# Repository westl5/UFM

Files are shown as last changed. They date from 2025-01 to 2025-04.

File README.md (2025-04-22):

# UFM - Unidentified Flying Mouse
**McMaster University Electrical & Computer Engineering Capstone Team 10**

<p align="center">
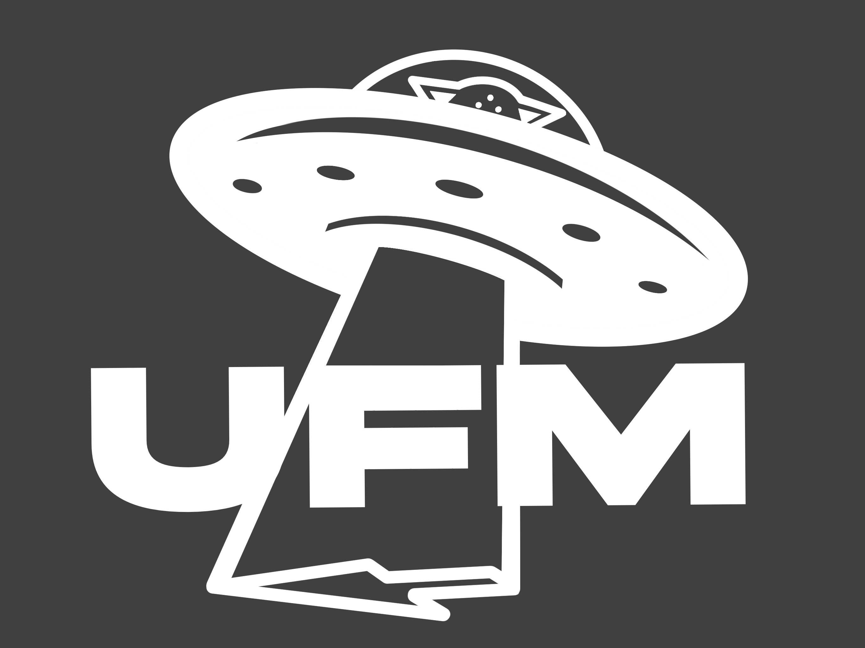
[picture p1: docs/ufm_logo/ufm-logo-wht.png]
UFM Logo
  
</p>

## Project Overview
UFM (Unidentified Flying Mouse) is a wrist-worn computer input device designed for individuals with limited hand dexterity, those who have undergone hand amputation, or those who were born without a hand. The system converts movements from the arm to mouse functions and sends mouse commands to the user's PC over bluetooth. 

## Project Video
https://github.com/user-attachments/assets/12428ccc-8710-40ed-a4b3-f343b9fc400c

([Full Video](https://youtu.be/52ZPP2TyDK4))

## Team Members
- Luke West ([@westl5](https://github.com/westl5))
- George Gill ([@georgegill](https://github.com/georgegill))
- Matthew Yu ([matthyu2002](https://github.com/matthyu2002))
- Ryan Xu ([@RyanXu02](https://github.com/RyanXu02))
  
## Contact
For more information about the UFM project, please contact any of the team members listed above.

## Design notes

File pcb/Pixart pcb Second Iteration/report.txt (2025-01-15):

Info: Processing symbol 'J2:'.
Info: Processing symbol 'U1:'.
Error: Cannot add J2 (no footprint assigned).
Error: Cannot add U1 (no footprint assigned).

Info: Total warnings: 0, errors: 2.

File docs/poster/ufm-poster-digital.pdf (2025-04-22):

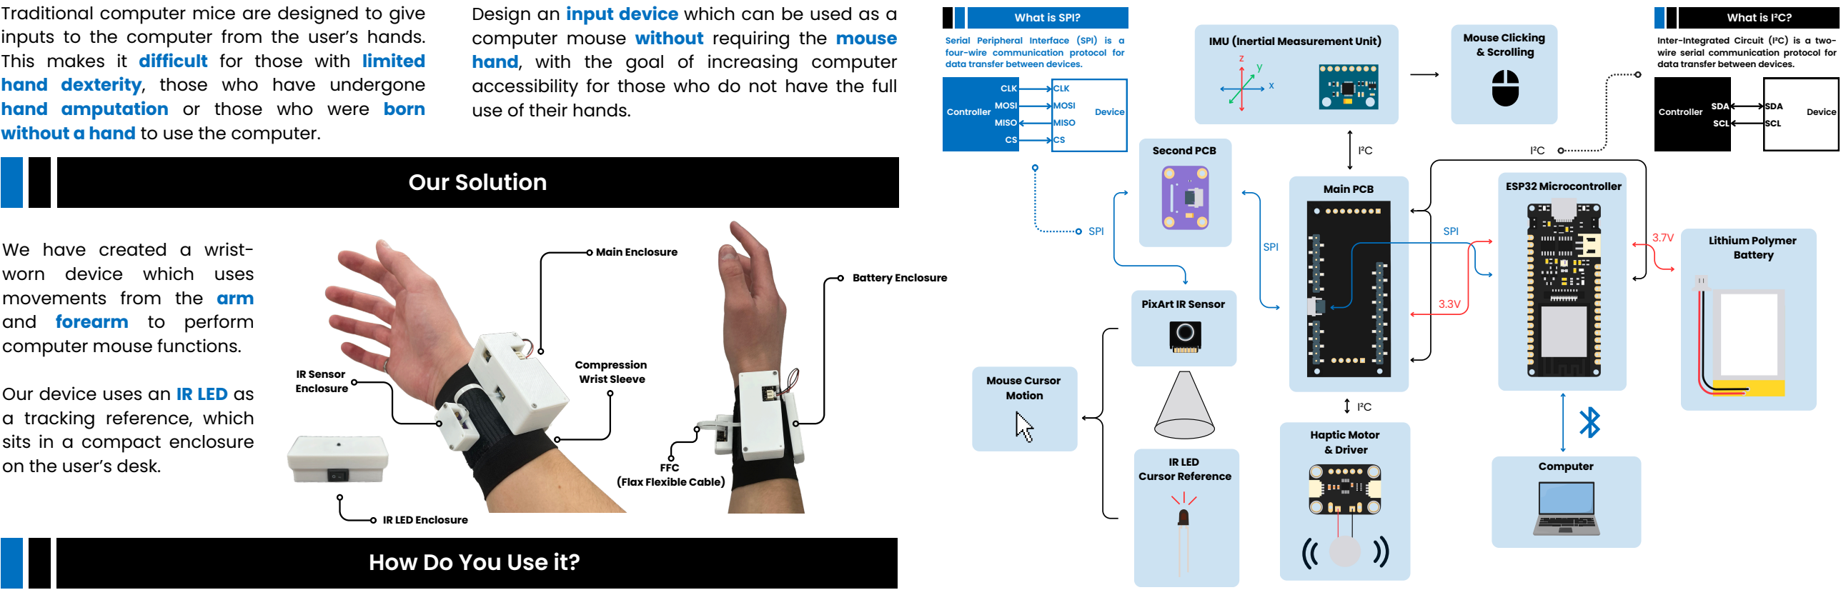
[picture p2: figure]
CLK MOSI MISO CS; ObjPercotbivleem; SPI; I²C; IMU (Inertial Measurement Unit); Main PCB; Haptic Motor & Driver; Computer; Lithium Polymer Battery; ESP32 Microcontroller; IR LED Cursor Reference; Mouse Clicking & Scrolling; Mouse Cursor Motion; PixArt IR Sensor; Second PCB; hand amputation or those who were born without a hand to use the computer.; use of their hands.; We have created a wrist- worn device which uses movements from the arm and forearm to perform computer mouse functions.; Our device uses an IR LED as a tracking reference, which sits in a compact enclosure on the user’s desk.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
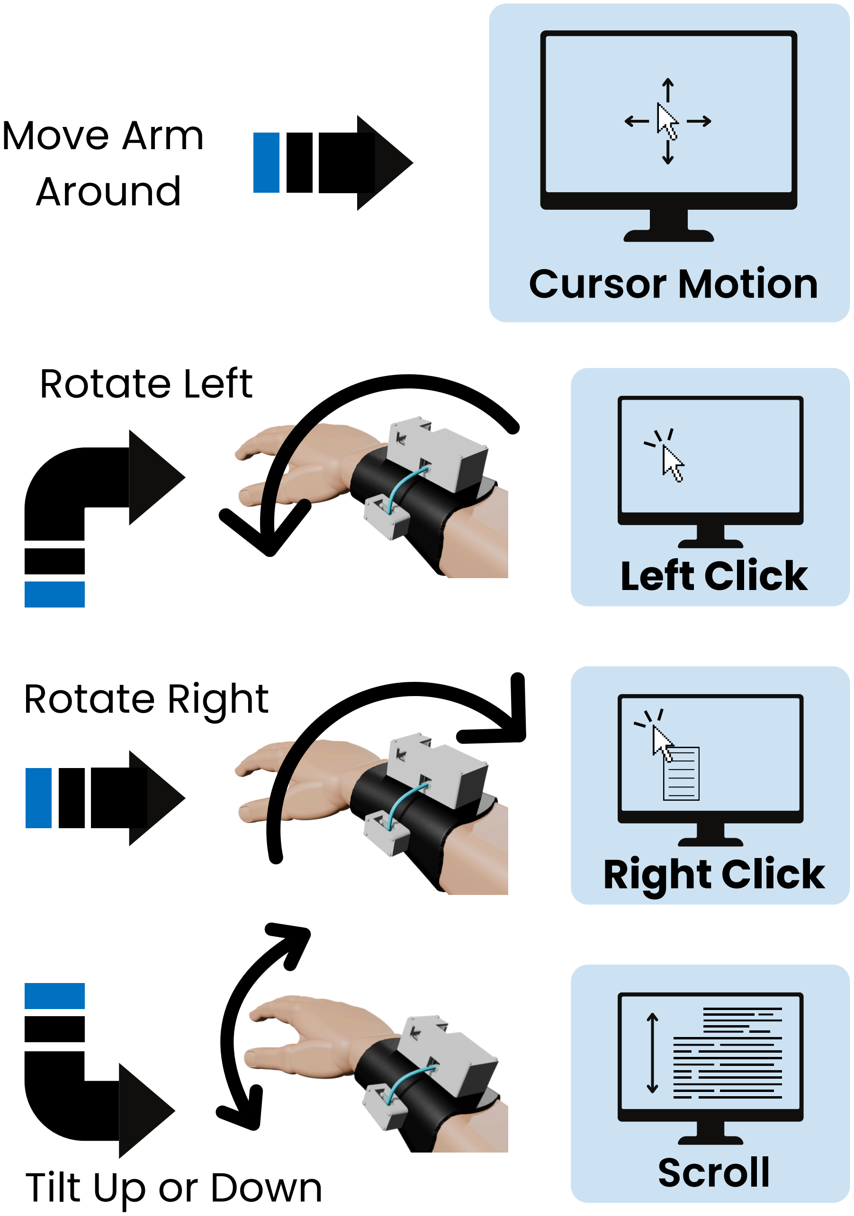
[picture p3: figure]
Move Arm Around; Cursor Motion; Left Click; Right Click; Scroll; Rotate Left; Rotate Right; Tilt Up or Down

### OObbjejeccttivivee

### OObbjejecctitvivee

References | + Video

### Motivation

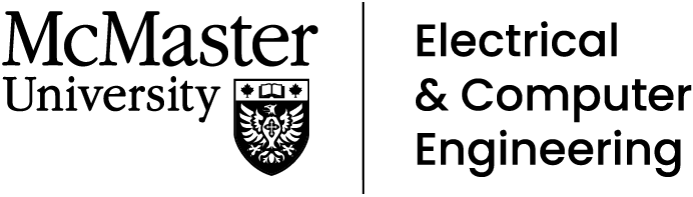
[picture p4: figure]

Hold Still (0.5s)

# unidentified flying mouse

### ECE Group 10 (Jom & Terry) - George Gill - Luke West - Ryan Xu - Matt Yu

### System Overview

### Project Video

Software Design Choices | Physical Design Choices

Traditional computer mice are designed to give inputs to the computer from the user’s hands. This makes it difficult for those with limited hand dexterity, those who have undergone

Design an input device which can be used as a computer mouse without requiring the mouse hand, with the goal of increasing computer accessibility for those who do not have the full

Inter-Integrated Circuit (I²C) is a two-

Small | form | factor | and | lightweight
construction for a comfortable fit. Compression sleeve allows users with various wrist sizes to put-on the mouse using only one arm.
Enclosures secured with velcro for easy attachment and removal.
Battery power allows for wireless operation for an estimated 8hrs with a 1100mAh LiPo battery.

### References & Acknowledgements

Codebase entirely contained to the ESP-32 meaning no extra software is needed from the user: Just pair with the device using bluetooth and the mouse is ready to use. Mouse movement calculation is very simple, allowing for low computation time and a very responsive mouse cursor.
Cursor movement is separated from other functions with a wait time, limiting mis-inputs.

How Does It Work?

Cursor Mode
(Default)

Gesture Mode
(User Prompted by
Haptic Vibration)

(If No Gesture,
Return to Cursor
Mode)

The PixArt IR Sensor Tracks an 850nm IR LED at 200fps and sends its x-y coordinates to the ESP-32 Microcontroller.
Each coordinate is compared to the previous one and the
difference is used to determine the direction and magnitude to of mouse movement to apply. If the mouse remains still for 0.5s, the user is prompted via haptic vibration to perform a gesture to click or scroll.
An IMU measures acceleration and angular velocity to capture each gesture.
The mouse cursor or gesture commands are sent to the PC by the ESP-32 over bluetooth.
Motivation | Objective
B. Trzynadlowski, “PixArt PAJ7025R2 6dof Tracking Demo with Arduino and Windows,” GitHub. Accessed: Jan. 03, 2025. [Online]. Available: https://github.com/trzy?tab=repositories&q=PixArt&type=&language=&sort=

University of Pittsburgh the McGowan Institute For Regenerative Medicine, “Prosthetic Hook Mouse for people with upper-limb amputations,” https://mirm-pitt.net/prosthetic-hook-mouse-for-people-with-upper-limb-amputations/ (accessed Oct. 20, 2024).

L. M. Keita, B. Alcantara, and M. G. Salazar, “Wireless Mouse for people with upper limb amputation,”://www.dlsu.edu.ph/wpcontent/uploads/pdf/conferences/ditech/proceedings/volume-3/paper-3.pdf (accessed Oct. 20, 2024).

Special thanks to the Thode Makerspace for providing resources such as 3D printers and soldering equipment.

[1]

[2]

[3]

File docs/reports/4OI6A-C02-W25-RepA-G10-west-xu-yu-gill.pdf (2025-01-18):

## ELECENG 4OI6A ECE Capstone Progress Phase A Ergonomic Computer Mouse for Individuals Lacking Hand Dexterity

Instructor: Dr. Abdelhadi
Section: C02
Group 10

Luke West – westl5 – 400310803 Ryan Xu – xur76 – 400309994 Matthew Yu – yum77 – 400322243 George Gill – gillg62 – 400327563

Date: January 17th, 2024

Table of Contents

## Abstract and Summary of the Design

The computer mouse is a common household tool which has very straightforward operation for most of the population. But for those with limited finger and hand dexterity, or those lacking a hand entirely, the traditional design can be difficult to use. We propose a wrist band mounted design, which eliminates the use of the hand entirely, placing emphasis on use of the forearm instead. Our design aims to accomplish all normal functions of the traditional mouse, namely cursor movement, clicking, and scrolling. The mouse movement is achieved by moving the forearm in the horizontal plane, clicking is achieved via rotation about the forearm axis, and scrolling is achieved via pitch angle of the forearm. Our device is controlled via ESP32 microcontroller, which takes input from a PixArt PAJ7025R3 multiple objects tracking IR sensor, and MPU 6050 inertial measurement unit, and sends mouse input commands to the user’s computer over Bluetooth (or UART via USB-C). The device also includes tactile clicking feedback via a haptic LRA motor.

## Current Status

## Implementation

The following is a list of notable achievements towards the project in phase A.
- Procurement of main components which are shown in the expenditure section
- Design and acquisition of PCB to interface with PixArt PAJ7025R3 sensor
- Successful communication with PixArt PAJ7025R3 sensor and 2D visualization of tracked objects
- Completion of overall circuit design and schematic
- Simulation of mouse cursor tracking in Python
- Demonstration of haptic feedback based on rotation of IMU
- Prototype 3D models of wrist band to hold all components, as well as an initial fourpoint 3D-model of structure to hold four IR LEDs
- Testing with ESP-32 Bluetooth capabilities, including moving a mouse cursor with pre-programmed movements

## Scheduling

The Gantt chart illustrates the project's progress over the last quarter of 2024. We are generally on schedule, with a few minor setbacks that have altered the forthcoming schedule. Setbacks from procuring parts and some issues interfacing with the PixArt sensor caused a significant delay in creating a working prototype. Additionally, this also halted the hardware/software assembly tasks.

This will cause a change in the testing stage, as we will cut into this phase to crash the uncompleted tasks. This is reflected in the new Gantt chart, where tasks "Develop

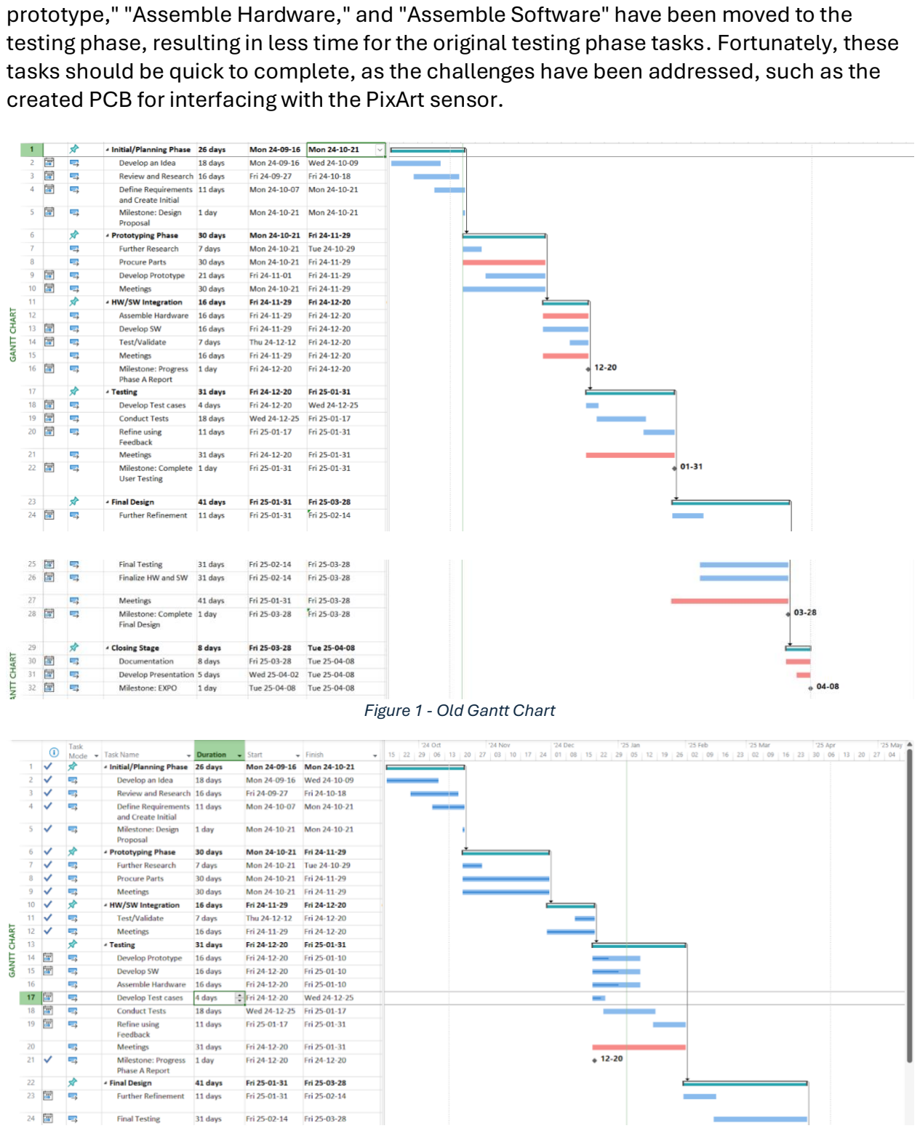
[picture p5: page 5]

prototype," "Assemble Hardware," and "Assemble Software" have been moved to the testing phase, resulting in less time for the original testing phase tasks. Fortunately, these tasks should be quick to complete, as the challenges have been addressed, such as the created PCB for interfacing with the PixArt sensor.

Figure 1 - Old Gantt Chart

Figure 2 - Updated Gantt Chart

## Expenditure

Current Spending

To date, our group has acquired the following components and materials essential to the prototyping and testing phases of the project. For price break down please see the bill of materials.

- Reflective Tape: Used to test how accurate the PixArt sensor tracks reflections from the IR emitter.
- IR Emitters & Receiver Package: Transmits IR for tracking purposes with the PixArt sensor.
- ESP32: Controller used for interacting with other devices and processing sensor outputs.
- Motor Unit: Provides user feedback through vibrations for interaction with the system.
- Motor Driver: Controls the motor units for providing feedback.
- Motor Driver Cable: Connects the motor driver to the system for signal transmission.
- PixArt Test PCB: Connects the PixArt sensor to the system as it does not come with a pre-made connector.
- Heat Resistant Tape: Protects components during the soldering process to avoid heat damage.
- Flux Paste: Improves soldering quality, ensuring clean and strong connections.
- IR Emitter (860NM): Offers a better NM rating for the sensor to detect, compared to previous emitters.
- PixArt Sensors: Main sensor for tracking movement in the system.

The total expenditure amounts to $260.16 CAD for the prototyping and testing phase of the project.

Team Member Personal Contributions & School Resources

Several team members have provided personal materials that they already owned to support the project which has significantly reduced overall costs. These materials include:
- Helping Hand Station for Soldering
- Soldering Iron
- Solder Wire
- Breadboards
- Capacitors
- Resistors
- Wires
- 3D Printer + Filament
- Makerspace Materials

Projected Future Expenses

Our team estimates an additional $200 CAD for the following:
- Custom PCB for wrist mounting (Possible flexible PCB)
- Purpose: To integrate all components into a compact, wrist friendly design. Flex PCB would improve comfort and durability.
- Smaller and more power efficient ESP32
- Purpose: Reduce size and device and extend battery life
- Flexible and comfortable material for wrist strap
- Purpose: Provide user-friendly and ergonomic strap so mouse can be used for prolonging periods of time.
- Battery
- Purpose: Power device while maintaining portability and compactness.

## Technical Implementation

## Physical Design

Circuit Design and Hardware

The electrical schematic created in KiCAD outlines the configuration of the microcontroller, sensors, and other components. Acting as a map, it will provide significant assistance during the physical wiring of the device. There are two critical aspects of the schematic. Firstly, the design that will be located on the wrist. This includes the PixArt sensor, microcontroller, haptic motor drivers, motors, IMU, and a battery. The microcontroller interfaces with all components through its various GPIO pins and is powered by an external lithium-polymer battery or USB-C cable connected to the computer. The KiCAD schematic closely follows the rough schematic, with slight tweaks. Additionally, our group checked if the FireBeetle2 and Adafruit E-Feather have similar configurations due to their benefit of onboard voltage regulator and noticed that the FireBeetle 2 is almost a perfect fit.

At the current stage, all testing is being done using a Node MCU development board which does not have built in battery implementation. We determined that an implementation including the battery is optional for the completion of the project, as a wired design has its own benefits, and allows for testing without draining a battery which could get expensive. In the later stages of the project, we intend to include a battery and communicate using Bluetooth, as this should be more physically comfortable for the user.

Note: The microcontroller used in the KiCAD schematic is the FireBeetle 2 ESP32-E. The FireBeetle 2 has an onboard voltage regulator, reducing the input voltage from the selected 3.7 volts to the desired 3.3 volts. It also has a built-in PH2.0 lithium battery connector interface and an on-board charging circuit, allowing easy battery charging using the USB-C port. This eliminates the need for an external voltage regulation circuit shown on the original rough schematic which would be required using the current ESP32 microcontroller development board, reducing the footprint of the schematic.

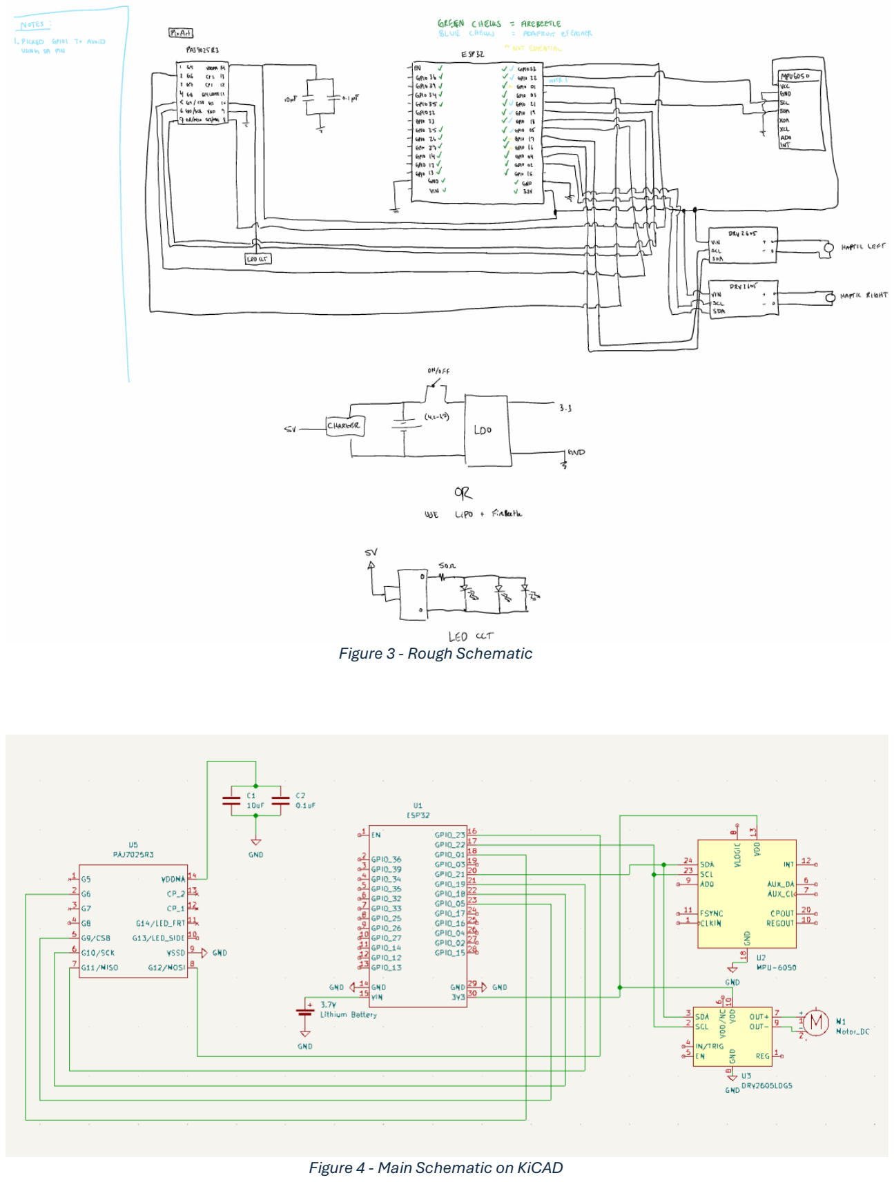
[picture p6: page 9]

Figure 3 - Rough Schematic

Figure 4 - Main Schematic on KiCAD

The second aspect of the schematic displays the IR LED circuit. The LEDs are configured in a parallel circuit and powered using an external lithium battery. Each diode has a 100-ohm resistor to limit the current to 8mA. The current can be altered using additional resistors if required. Lastly, a switch controls if the circuit is active, allowing the user to turn on/off the circuit accordingly. This schematic may undergo changes in the future following the prototyping stage.

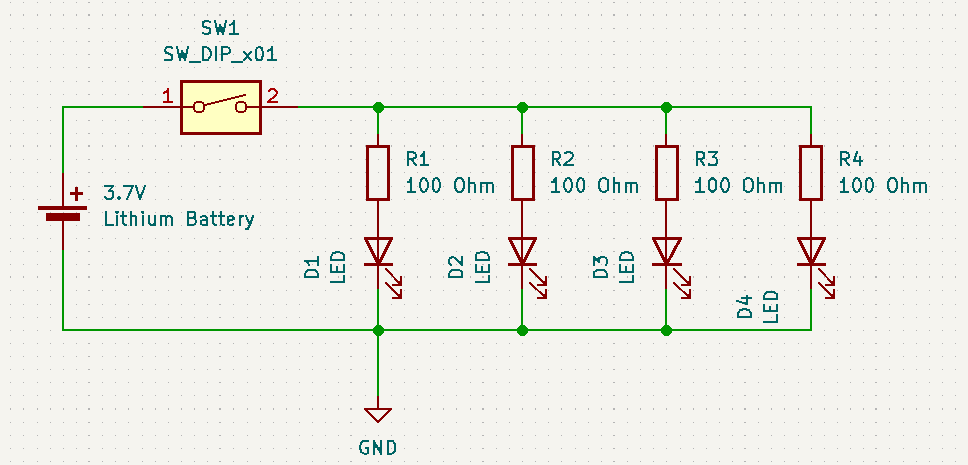
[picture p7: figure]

Figure 5 - Schematic of IR LED Circuit on KiCAD

PixArt Custom PCB Design
In the early stages, our group struggled to interface with the PixArt PAJ7025R3 sensor due to limited knowledge and a lack of pre-made connectors. The datasheet provided minimal guidance, leaving us uncertain about how to proceed. Eager to advance, we tried various methods, including soldering wires directly, creating a custom connector, and reaching out to companies for support. However, these attempts failed, and one sensor was damaged in the process. The long lead time for a custom PCB added further delays, but we ultimately determined that designing a custom PCB was the most reliable solution. A project by Bart Trzynadlowski using the PAJ7025R2 variant of our sensor was referenced in the design[1].
From doing research, our group decided to learn KiCAD to design the PCB as it is known as a beginner friendly software. The custom PCB that was created includes:
- Two-layer construction: A compact and efficient layout for seamless integration. Custom through-hole connector: Designed to provide a stable and secure connection to the sensor.
- Pin header connection: Precision-routed traces ensuring reliable communication between the sensor and the system.
- Clear labeling: Each trace and pin has been clearly labeled to improve assembly accuracy and facilitate future troubleshooting.

This process not only addressed the immediate need for a stable connection to the sensor but also significantly enhanced my skills in PCB design. Despite the initial setbacks, this solution enabled us to move forward with the project, exemplifying our ability to overcome technical challenges through proactive problem-solving and innovation. The experience has been invaluable in ensuring that our system is both reliable and scalable as we continue development. An image of the PCB design can be found below with more details of the design in the appendix.

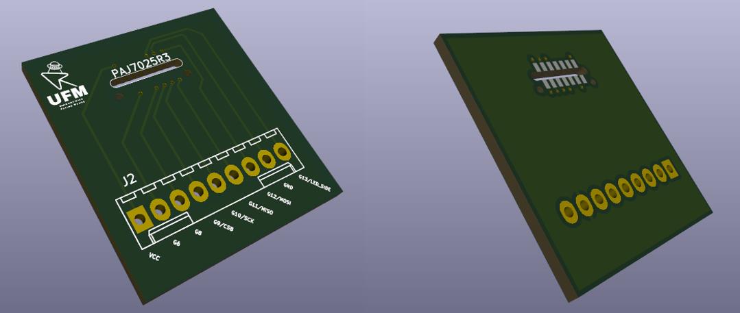
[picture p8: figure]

Figure 6 - Custom PixArt Sensor PCB Front and Back View Iteration 1

PixArt PCB Redesign
After a two-week lead time, the PCBs were delivered, and our team successfully soldered the sensor onto the custom design. This first iteration of the PCB was intentionally overdesigned to account for all potential pin configurations we deemed useful for the sensor. However, through extensive testing and prototyping, we identified several opportunities for optimization:
1. Pin Reduction: Of the original 9 pins, only 6 were necessary for the sensor’s operation, allowing us to simplify the design and reduce unnecessary traces.
2. Proximity of Capacitors: Following recommendations from the sensor’s datasheet, we ensured that decoupling capacitors were placed as close to the sensor as possible to improve signal stability and reduce noise. Proper placement of capacitors is critical for mitigating power supply fluctuations and ensuring consistent performance [2].
3. FFC/FPC Cables: To enhance flexibility and reduce weight, we transitioned from traditional pin headers to flat flexible cables (FFC) and flexible printed circuits (FPC). These components are significantly thinner and more compact, making them ideal for wearable applications where size and weight are critical considerations [3], [4].
4. Mounting Holes: Strategically placed mounting holes were added to secure the PCB within the 3D-printed housing, ensuring stability during operation [5].

Capacitor Selection
For the second iteration, we added two capacitors to the design: a 10 µF capacitor and a 0.1 µF capacitor. The selection process for these components was crucial to optimizing the PCB's performance. Here is an overview of the types of capacitors we considered and the reasoning behind our final choice:
- Ceramic Capacitors:
- Pros: Compact, low cost, and excellent frequency response. They are ideal for decoupling applications due to their low equivalent series resistance (ESR).
- Cons: Limited capacitance range, and their capacitance can vary with voltage (known as the DC bias effect).
- Tantalum Capacitors:
- Pros: High capacitance in a small form factor, stable performance, and low leakage current. They are well-suited for applications requiring bulk storage and stability.
- Cons: More expensive than ceramic capacitors and can be sensitive to voltage spikes, potentially leading to failure.

- Electrolytic Capacitors:
- Pros: High capacitance values and relatively low cost. Suitable for bulk storage.
- Cons: Larger size, shorter lifespan, and higher ESR compared to other types.
- Film Capacitors:
- Pros: Very stable and reliable, with excellent tolerance.
- Cons: Large size and relatively high cost, making them unsuitable for compact designs.

We ultimately chose a ceramic capacitor (0.1 µF) for decoupling due to its excellent frequency response and low ESR, which are crucial for filtering out high-frequency noise. For bulk capacitance, we opted for a tantalum capacitor (10 µF) due to its small form factor and stable performance. This combination balanced cost, size, and functionality [2].

Connector Selection: FFC vs. FPC

Transitioning to FFC/FPC connectors significantly improved the compactness and weight of the design. These connectors are widely used in applications requiring thin, flexible connections.
- Flat Flexible Cables (FFC): Comprised of flat and flexible ribbon-like cables, FFC connectors are simple to use and cost-effective[3], [4].
- Pros: Low profile, highly flexible, and widely available in standard configurations.
- Cons: Limited durability and can be prone to damage if handled improperly.
- Flexible Printed Circuits (FPC): Like FFC but more robust, FPC connectors use circuits printed directly onto a flexible substrate [3], [6].
- Pros: Higher durability, better electrical performance, and customizable configurations.
- Cons: More expensive and requires precise manufacturing processes.

For our application, FFC was chosen due to its simplicity and cost-effectiveness, aligning with the lightweight and compact nature of our design.

When it came to picking the type of FFC connector, there were a plethora of them to look at. Our team considered the pros and cons of each locking feature:
- Back lock: A simple, rear-entry locking mechanism where the cable is inserted and locked by engaging a mechanism at the back of the connector.
- Pros: Provides a solid, secure lock with low chances of accidental disconnection. It’s also relatively straightforward and easy to implement.
- Cons: In some designs, it might be harder to disengage or re-connect, especially in tight spaces.

- Flip lock: A locking mechanism where a flap or lever is flipped over the cable to lock it in place.
- Pros: Simple to use and offers a quick connection. It’s also quite secure in some designs.
- Cons: Can be bulky, and the flipping motion might wear out over time, especially in high-usage applications.
- Flip lock, Back lock: Combines the flip mechanism with a back-locking feature to secure the cable.
- Pros: Provides both secure locking and ease of assembly/disassembly.
- Cons: Combining both mechanisms can lead to a larger connector footprint, potentially affecting space and weight-sensitive designs.
- Latch Lock: A latch engages to lock the connector in place, often requiring the latch to be pulled or pressed to disengage the cable.
- Pros: Ensures a firm connection, preventing the cable from accidentally detaching.
- Cons: Can add complexity to the connector, potentially requiring more force to disconnect, and may not be as compact as other options.
- Rotary Lock: The cable is inserted into the connector, and a rotary mechanism is used to twist and lock the connector in place, ensuring a tight, secure fit.
- Pros: The rotation provides a strong, mechanical engagement, making the connection extremely stable. It's resistant to vibrations and accidental disconnections.
- Cons: It requires a bit more effort to engage and disengage compared to simpler mechanisms.
- Rotary Lock, Back lock: Combines the rotary mechanism with the back lock feature to create an even more secure connection.
- Pros: Offers a very secure connection, combining the mechanical stability of the rotary lock with the added safety of the back lock. This ensures the cable remains firmly locked in place, even in high-movement or vibration-prone environments.
- Cons: Can be bulkier than some other locking mechanisms, and the combined mechanism may require additional space or assembly effort.
- Slide Lock: A slide mechanism locks the connector by sliding a piece over the cable.
- Pros: Quick to engage and disengage, with minimal effort required.
- Cons: May not offer the same level of security as other locking mechanisms, especially in high-vibration environments.

We chose the Rotary Lock, Back lock mechanism for its combination of security, compactness, ease of use, and durability. Its rotary feature ensures a stable, tight connection that resists accidental disconnections from vibrations or mechanical stress, which is crucial for our wearable design. Despite its strength, it adds minimal bulk compared to other locking mechanisms, helping maintain a lightweight and unobtrusive design. The back lock adds an extra layer of security, ensuring the cable stays securely locked even under light pulls or movements. Additionally, its robust design ensures longterm reliability, reducing wear and tear from regular use [6].

NPT vs. PTH (Non-Plated Through-Hole vs. Plated Through-Hole)

When adding mounting holes, we considered the difference between NPT (Non-Plated Through-Hole) and PTH (Plated Through-Hole) designs:

- Non-Plated Through-Holes (NPTH):
- Pros: Easier to manufacture and more cost-effective for applications where electrical connection is not required.
- Cons: Not suitable for carrying signals or power.
- Plated Through-Holes (PTH):
- Pros: Allow for electrical connections between layers and provide mechanical strength.
- Cons: More expensive and complex to manufacture.

For our mounting holes, we chose NPTH since they only serve as mechanical supports and do not require electrical connectivity [5], [6].

Results

With these refinements, the second iteration of the PCB included:
- 1 x 10 µF tantalum capacitor
- 1 x 0.1 µF ceramic capacitor
- 1 x FFC connector
- 4 x NPTH mounting holes

By reducing the number of traces and using a smaller connector, we scaled the PCB down from 28 mm x 30 mm to 18 mm x 20 mm, even with the addition of two capacitors. This miniaturization represents a significant milestone in ensuring the device remains wearable and unobtrusive.

The iterative process not only improved the PCB’s functionality and design but also highlighted the importance of component selection and user-driven refinement in achieving project goals. The redesign of the PCB along with 3D models of the electrical components are shown below with more information found in the appendix:

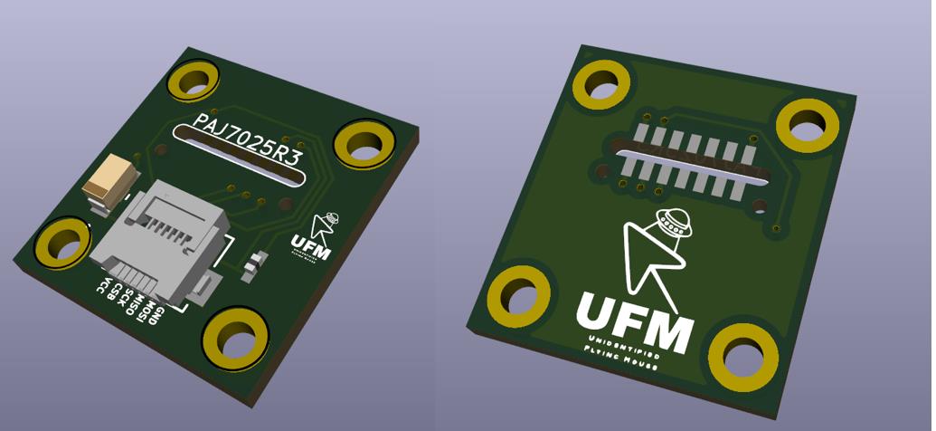
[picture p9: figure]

Figure 7 - 3D Render of Custom PixArt Sensor PCB Front and Back View Iteration 2

Procurement of Additional PAJ7025R3 Sensors
After damaging one of the two original sample sensors, our group decided to purchase more as a contingency if we damaged the second sensor. This proved more challenging that we initially thought, as the sensor is not carried by typical consumer level vendors such as Digikey or Mouser. After discussion with PixArt, they informed us that direct orders would only be available in bulk, with a minimum number of 90 sensors. Furthermore, we were informed that due to a change in manufacturing, ordering directly from PixArt would result in an order not being shipped until February. As this is well outside our price range, too long of a lead time and an unnecessary number of sensors, we investigated other alternatives. The options were sparse, and after communication with some vendors, we were eventually able to order a more appropriate sample size of 5 sensors from Codico, a company based in Europe. It required some communication with the McMaster ECE department as well to complete the order, as Codico only takes orders business to business. These additional sensors were delivered to McMaster, and our group was able to pick them up on January 8th

Wrist Band Design

The wristband design focuses on creating two enclosures, one for the camera mounted on the side of the wrist and a second to hold most of the components on top of the wrist. We decided to separate the design into two compartments instead of a single enclosure, due to size regulations of the average wrist size. Firstly, we predefined the key needs to address this aim, such as ensuring the design is secure, comfortable, lightweight, and safe. The most important factor is comfortability, as the design should be ergonomic and accommodate prolonged use. Additionally, the design should be securely mounted on the wrist and durable to hold the fragile components, protecting it from minor wear and tears. Moreover, the design should be safe, with multiple holes for heat dissipation and no sharp corners. Lastly, the size and weight were considered. The wristband should be adjustable and accommodate wrists of 14 cm to 22 cm in circumference, utilizing a clamping method that can be mounted using a single hand. Typically, an average watch weighs around 120 grams. Our goal was to keep the weight constrained to 150 grams or less. The total weight of all our components is around 70 grams, however, to streamline the process we left out the battery and a haptic driver, resulting in the total weight of the components being only around 50 grams. This provides around 100 grams for the wristband itself.

In later stages of the project, the inclusion of a battery will require a small redesign of the enclosure. The added battery would be a 550 mAh lithium polymer battery, whose size roughly matches the dimensions of the existing enclosure (50.5 x 34 x 3 mm) and would only add around 10g to the weight of the wristband. At 550mAh, we estimate this would translate to roughly 3 hours of use before needing to recharge, assuming the ESP32 consumes a constant worst case ~200mA on average (150 mA for RF communications, 6mA for the MOT sensor, 4mA for the MPU6050, 30 mA for haptic motor, rounded up to 200mA) [7]. A more detailed component selection for the battery still needs to be made. There are also numerous power optimizations, such as sleep mode, which can improve battery life.

Next, a CAD prototype was created to visualize a potential design, constructed using Autodesk Inventor. The wrist enclosure is a simple (55mm x 36mm x 14mm) box. The enclosure features a two-piece assembly consisting of a box and a lid, fastened together with M2 fasteners and heatsinks. This small footprint was achieved by stacking the ESP32 on top of the other components, resting on four pillars. The IMU and Haptic Driver, sit under the microcontroller, with designated mounting holes to ensure they are snugly in place. The small opening at the bottom of the box is for the motor to sit in and directly contact the skin, for optimal haptic feedback. We considered adding a protective membrane between the user's skin and the motor, this may be implemented in the future depending on our feedback. Additionally, there are two slits in the box, one for the wires which interface with the camera, and another for connecting to the microcontroller itself. These slits also provide ventilation for heat to safely dissipate.

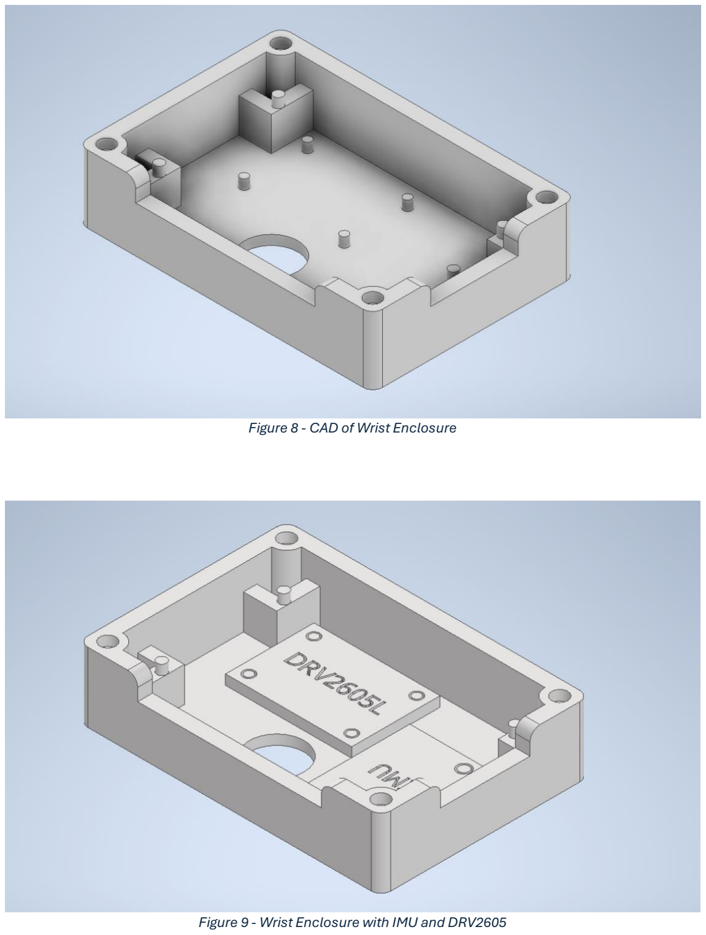
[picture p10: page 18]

Figure 8 - CAD of Wrist Enclosure

Figure 9 - Wrist Enclosure with IMU and DRV2605

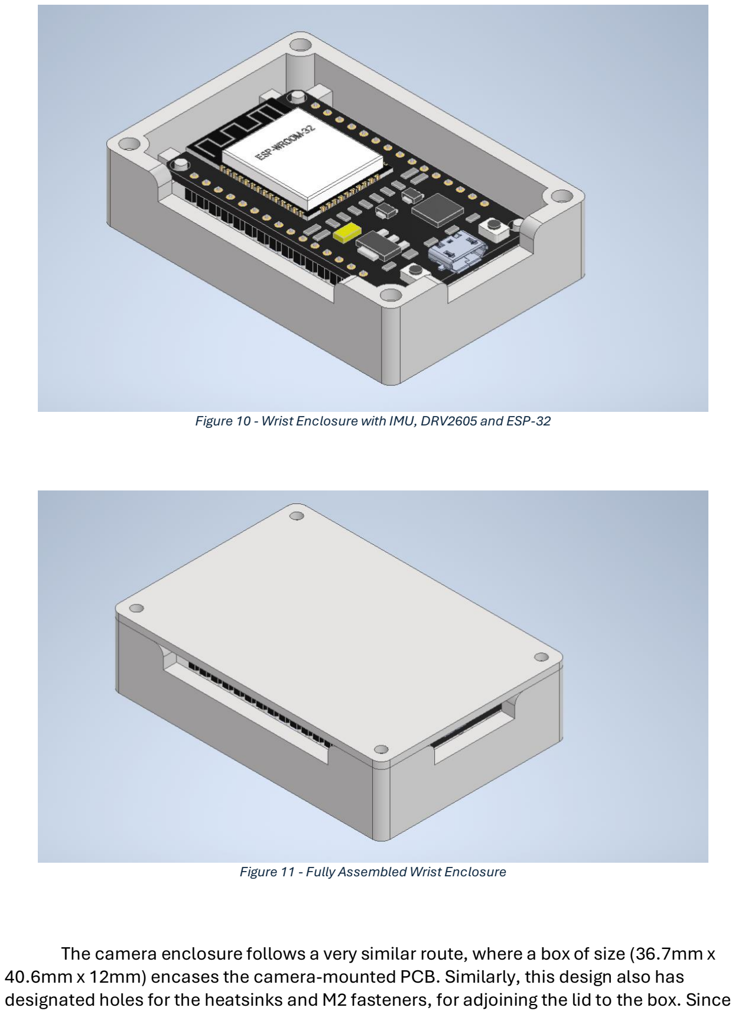
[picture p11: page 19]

Figure 10 - Wrist Enclosure with IMU, DRV2605 and ESP-32

Figure 11 - Fully Assembled Wrist Enclosure

The camera enclosure follows a very similar route, where a box of size (36.7mm x 40.6mm x 12mm) encases the camera-mounted PCB. Similarly, this design also has designated holes for the heatsinks and M2 fasteners, for adjoining the lid to the box. Since

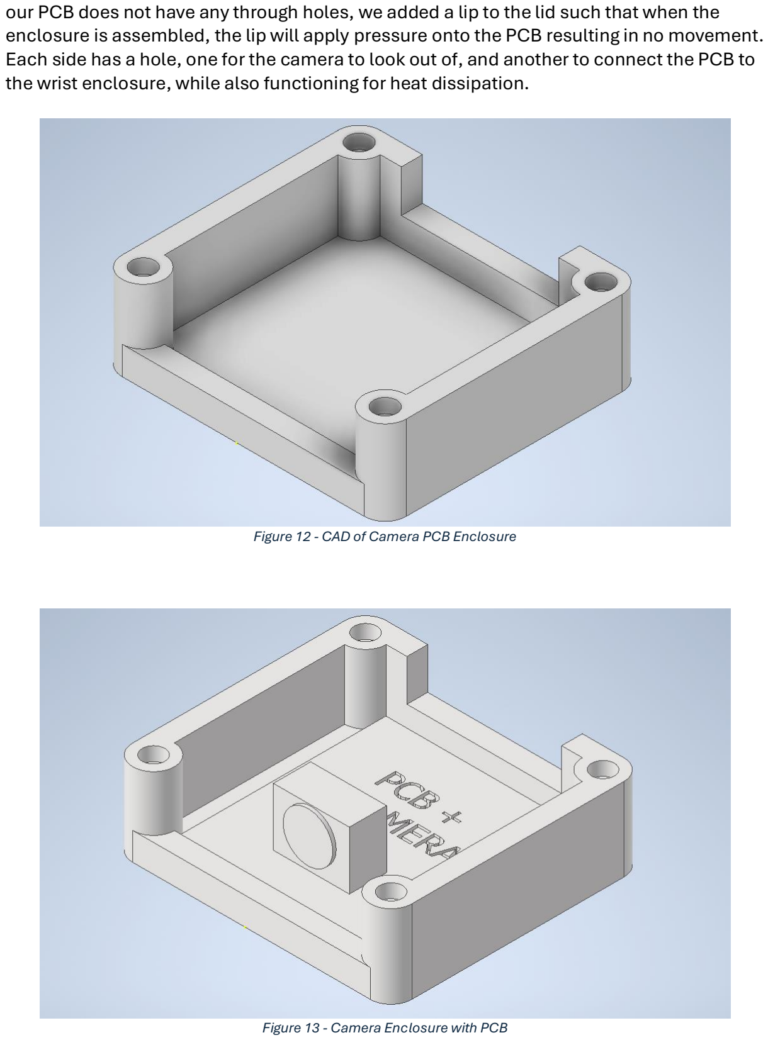
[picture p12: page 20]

our PCB does not have any through holes, we added a lip to the lid such that when the enclosure is assembled, the lip will apply pressure onto the PCB resulting in no movement. Each side has a hole, one for the camera to look out of, and another to connect the PCB to the wrist enclosure, while also functioning for heat dissipation.

Figure 12 - CAD of Camera PCB Enclosure

Figure 13 - Camera Enclosure with PCB

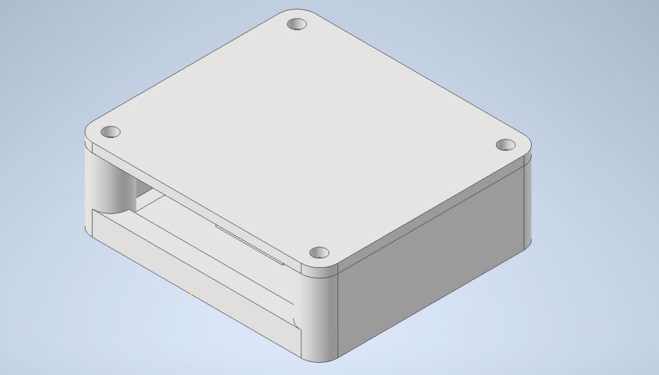
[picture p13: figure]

Figure 14 - Fully Assembled Camera Enclosure

Both enclosures will be securely mounted to a wristband, with a simple strapping mechanism. As seen in the figure below, the larger enclosure housing the ESP-32 sits on top of the user’s wrist, and the camera enclosure sits to the left of it, with a ribbon of wires interfacing the two together. These wires will be long, providing enough slack for users with larger wrists. Initially, we decided to position the camera enclosure at the bottom of the wrist, however decided against it due to all the force being in a single direction. This positioning takes a little bit of stress off while maintaining a clear view of the LEDs below. The wristband design and strapping mechanism will be considered in the near future as we develop a better understanding of the design.

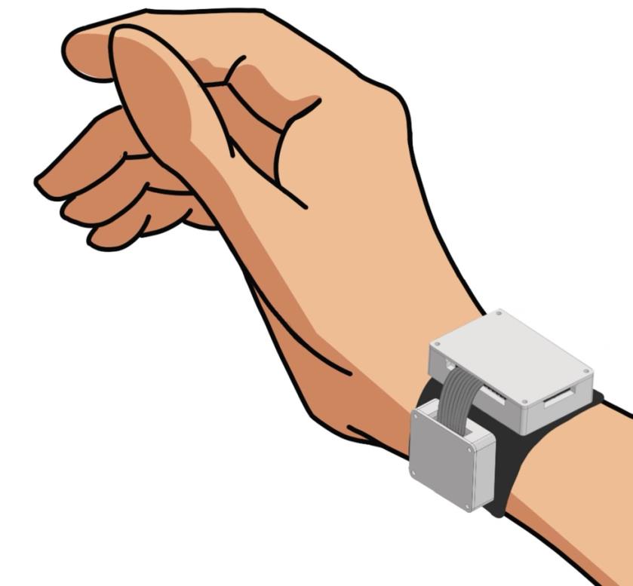
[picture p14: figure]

Figure 15 - Detailed Sketch of Wrist Band Design

A dedicated CAD model for the standalone LED circuit was also created using Autodesk Inventor. This model is a straightforward box with four holes in a square pattern for the IR LEDs. The distance between these was set at 100mm to ensure the LEDS do not interfere with each other. However, this distance may need to be increased/decreased depending on how the PixArt sensor interprets each instance. This enclosure holds the four IR LEDs, four resistors, and a battery. The only constraint for this model is the size, as we want to minimize the total footprint of our design for usability purposes.

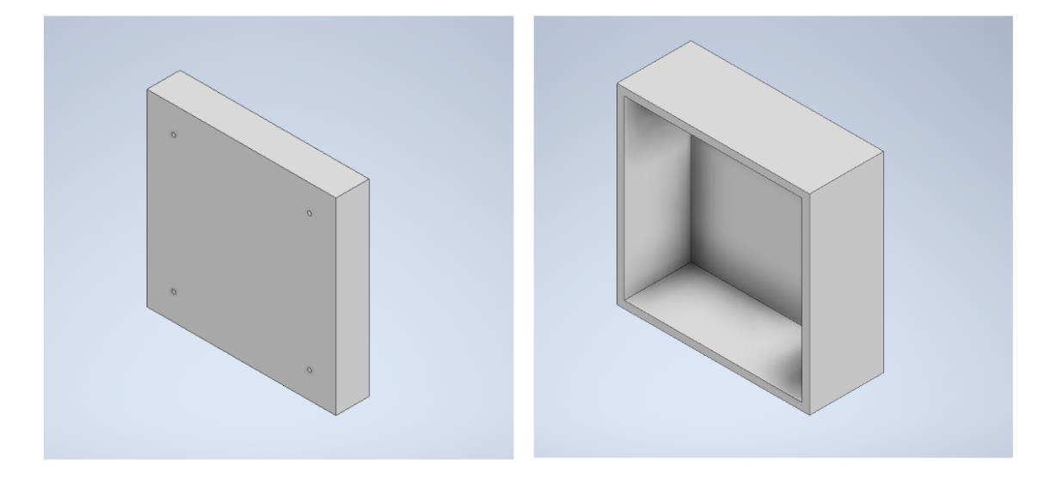
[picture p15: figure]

Figure 10 – CAD of IR LED Circuit Enclosure (base on right, Lid on left)

The next step is to 3D print this design and initiate testing to evaluate the requirements. This includes ergonomic, durability and comfortability testing. The feedback collected will adjust the design to meet the specified requirements more closely.

## System Design

Flowchart/State Diagram
The following state diagram showcases the basic logic of the functionalities of the device. The device will keep a neutral roll angle of the wrist (as shown in Figure 15) to compare its current angle and depending on the angle deviation from the neutral roll angle, the device will enter different states to perform different functions. Scrolling can be performed via a different axis of movement, which we’ve picked to be the pitch the device. This means simply tilting your forearm to point at or away from the surface/desk could scroll the mouse up or down.

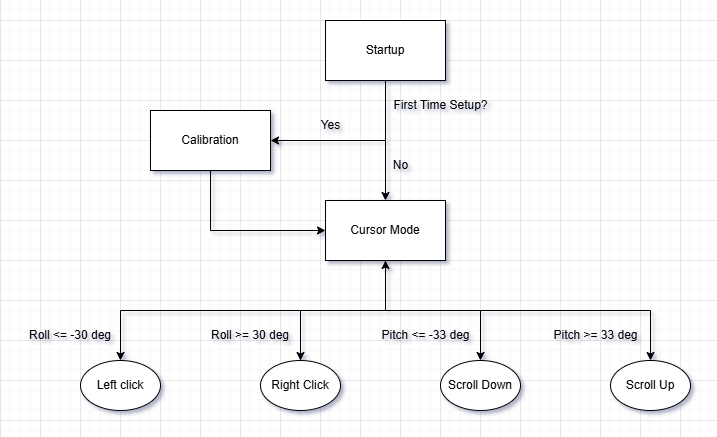
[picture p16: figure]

Figure 11 – Flowchart/State Diagram
The actual conditional values for the roll angles are only placeholder values currently, as more testing is needed to possibly determine better and more ergonomic values to enhance user experience. Calibration is also in a placeholder stage simple for ease of development, as the device will most likely require a calibration stage in later stages of development, as seen in the calibration of the IMU, that needs to take a base measurement first to determine the angular offsets correctly.

## Monocular Point Tracking and Mouse Cursor Movement

Physical Setup and Working Principle
There are two main hardware components used to achieve mouse cursor motion: the PixArt PAJ7025R3 MOT (multiple objects tracking) sensor, and a cluster of 850nm IR LEDs. The MOT sensor contains a camera with an 800-900nm IR pass filter as well as built in hardware to track up to 16 objects. It assigns a number to each object and returns the coordinates of each point to the micro using SPI.

To obtain cursor motion, the 3D coordinates of the sensor relative to the cluster of LEDs must be obtained using only the 2D point coordinates obtained from the MOT sensor, and the intrinsic parameters of the sensor’s camera. To accomplish this, multiple approaches were researched and explored. There are two projects documented on GitHub using the same MOT sensor which were used as main inspirations for this project: Retrosphere, which uses a stereo setup built into glasses to track reflective spheres for various VR and AR applications, and a 6dof demo by Bart Tryznadlowski which uses a monocular setup to model motion of a real ping pong paddle in 3D Click or tap here to enter text..

The main advantage of a stereo setup is that depth information is easier to obtain and more accurate, leading to more accuracy in the 3D tracking. In our project, a monocular approach is adopted, because the hardware setup is less complex and simpler to mount to a human wrist. Rather than using the known distance between two cameras, the known dimensions of a cluster of LEDs is used to determine camera pose in 3D. There are many approaches for achieving this that were explored, but eventually, the PnP solver in opencv was chosen [9].

This algorithm takes a set of known world coordinates (in our case the point cluster), a set of 2D points as seen in the camera, and the camera’s intrinsic matrix and distortion coefficients. Then, it computes the rotation and translation required to correspond the 2D camera points to the 3D world points. This can then be used to recover the camera’s pose in the world frame.

Simulation and Testing Results
As explained in the hardware design section of this report, our group faced challenges in interfacing with the PixArt MOT sensor. Thus, to test the theory required for the project, a simulation was written in Python using OpenCV. The camera is simulated using an intrinsic matrix created from the datasheet parameters of the PixArt PAJ7025R3. A 3D points cluster is created, and the points are projected onto a 2D plane using the
cv. projectPoints() function. Then, the camera pose is recovered using OpenCV’s PnP (Perspective-n-Point) algorithms. The x and y coordinates of the camera position are then used for cursor movement, and a simulated cursor is plotted on a 1920x1080 screen. As an added feature, a function adding random gaussian noise to the camera points was also created to simulate real word noise and monitor its effects, but for the plots shown below, noise was neglected to show a clean result. This effect will be explored further while implementing the algorithm with the actual sensor.

Various point clusters were tested for accuracy of recovering the camera pose. At first, a rectangular pattern like that in Bart Tryznadlowski’s project was used, however, because of the symmetry of the rectangle, mirror solutions are often returned [1]. These cases can be handled explicitly and will require more investigation. Furthermore, although the points being coplanar does decrease depth information of the object, this method does offer the advantage of a simpler setup that involves less LED occlusions (when one LED covers another LED) to consider. Because of this, this method will be the first method explored in the physical implementation, as it is the simplest to test. An example of a simulation using the rectangular structure is shown below:

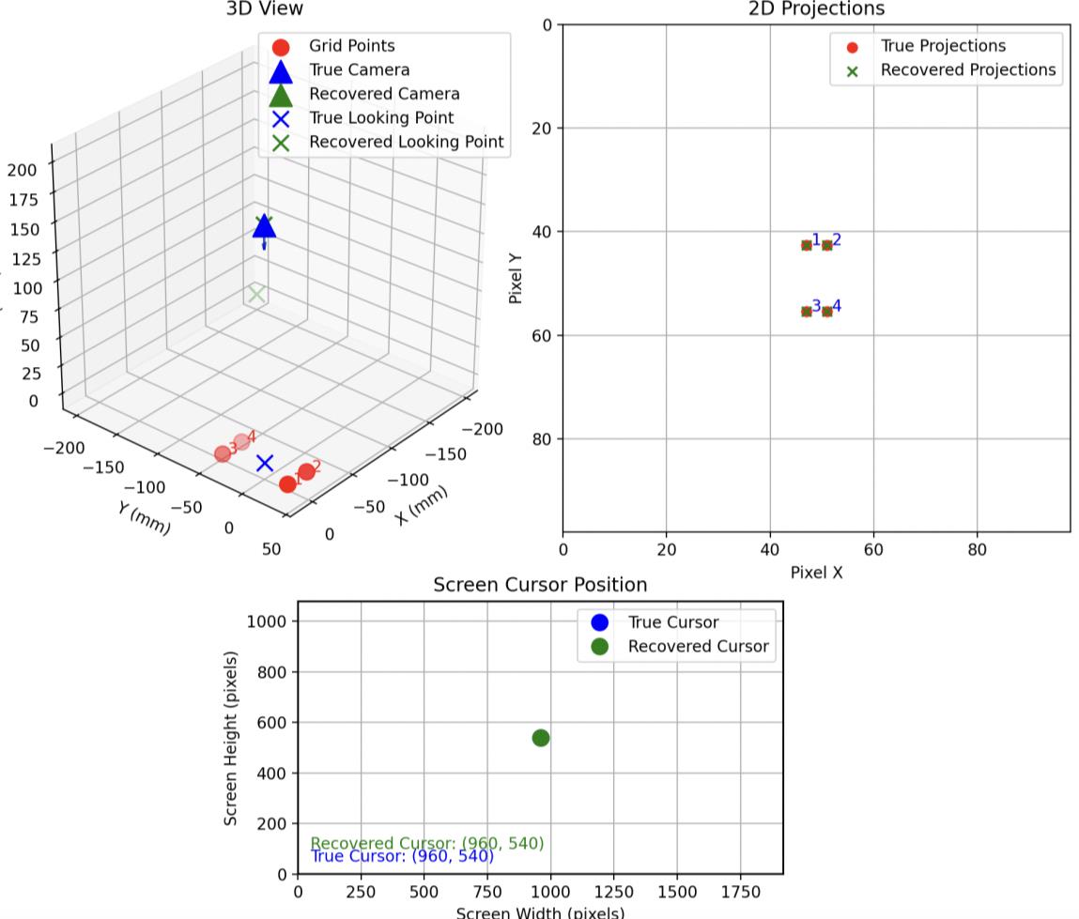
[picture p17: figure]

Figure 16 - Simulation Using Rectangular LED Object

To improve the accuracy, a 6 LED structure was also generated with a coplanar triangular base, and varying LED heights and locations. A 9 LED structure was also explored, using 5 coplanar points as the base and 4 other points with varied height, however the six LED configuration is preferred as the build complexity is reduced.

Varying the heights of the LEDs in the cluster helps provide depth information, but also decreases the range of motion, as occlusion occurs more frequently. Another thing to consider with the LED structure is that at lower height differences, it is more difficult to physically build, since our budget and build quality requires high error tolerance. Shown below is an example where the camera is directly above the Six LED structure:

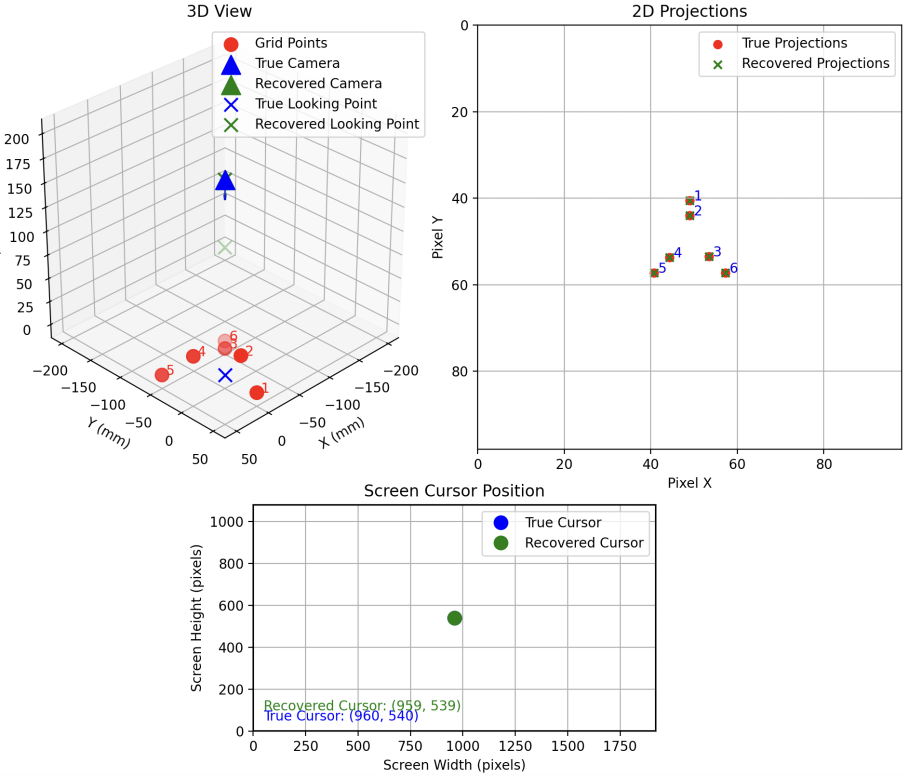
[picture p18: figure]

Figure 13 – Simulation Using Six-LED Object

Obstacles
There were several obstacles encountered when trying to create the simulation. First, learning about camera properties and the area of computer vision proved challenging, as this area was well outside my initial scope of knowledge and included a lot of math which was difficult to understand at first. Furthermore, methods from scratch based on the algorithms presented in various papers were attempted, such as BKP Horn’s method for absolute orientation and a three-point head pose tracking algorithm for tracking LEDs mounted on glasses with a camera [10], [11]. However, this proved time consuming, and in the end, it was much more beneficial to use the OpenCV library, which contains a plethora of methods to use in both python and C++. Nonetheless, reading the literature was very beneficial overall learning, and helped in understanding the scope of what is required for the project. It may also prove useful when optimizing the computation time on the microcontroller if the OpenCV methods prove to be too computationally expensive.

One upcoming area which is anticipated to be a challenge is utilizing the methods from the simulation in the actual physical sensor and microcontroller implementation. Firstly, it may prove challenging to run on ESP32, as the computation may be time consuming enough to cause noticeable lag. Furthermore, converting the code from python to C/C++ should be feasible, but will present some differences. Ideally, all computations should be done on the microcontroller, however in a worst-case scenario, the ESP32 could simply be used to transmit data to the user’s PC to perform the computations on a more robust device.

Another potential challenge is handling camera distortion. OpenCV models distortion using a polynomial with coefficients for radial (k1, k2, …, k6) and tangential distortion (p1 and p2). From the PixArt datasheet, the -30% distortion was assumed to mean radial distortion only, so the first order radial coefficient k1 was set to -0.3. This may not necessarily be the case, and this issue can be solved by calibrating the camera to retrieve its intrinsic properties. This is typically done by taking several images of a grid pattern, however, since the PixArt sensor returns coordinates of up to 16 IR objects, a different calibration method will need to be used. This may need to be explored to accurately find the sensors position.

Next Steps
The following are the steps required to achieve a functional mouse cursor:
- Improve recovery of camera looking direction, as this becomes more inaccurate as the camera rotation increases. If this is not possible, rotation will be handled entirely with the IMU, while the PixArt sensor will handle 3D position.
- Python was used for easy plotting; however, it cannot be used on ESP32. Instead, convert to code which can run on ESP-32 to do computation on the microcontroller

(C/C++/Arduino), and interface with actual sensor and IR LEDs. Since OpenCV is a c-built library, this should be possible.
- Currently, occlusion is handled by setting limits which remain inside a zone where the LED are not occluded. Rather than avoiding occlusion, try to handle the cases where it occurs. This was done using a neural-network approach in the Retrosphere project, so it is an area which should be investigated for robustness of the design.
- The design should better handle the case where one or more LEDs are not visible to the camera.
- The case where the sensor loses track of an LED must be explicitly handled.
- The minimum amount of current through the LEDs while still producing a bright enough light shall be explored in the real implementation.
- Other methods of camera calibration compatible with the PixArt sensor should be explored and tested.

## PixArt MOT Sensor Testing and 2D Visualization

Interfacing with the PixArt sensor proved more complicated than initially expected, as the sensor has numerous registers which need to be written to and read from over SPI to both initialize the sensor but also continuously read object data. Using code from Bart Trzynadlowski’s code as a base, firmware was developed to communicate with the sensor using the ESP-32 and send object data over serial UART [1]. The code initializes the sensor according to explicit steps in the datasheet (our group has signed an NDA and is therefore unable to share the datasheet for the PixArt PAJ70253 sensor). The code was meticulously analyzed line by line to ensure all steps were made according to the datasheet. The code was commented to show functionality of each register and what each step does according to the datasheet.

The first testing step was to read one of the test images pre-stored in the sensor. These images were helpful to determine whether the sensor worked without needed any LED circuit. Once the sensor was confirmed to be functional, a circuit using a single
OSRAM SFH 4356 860nm IR emitter was quickly made on a breadboard and supplied using a DC voltage from the AD2. Once it was determined that the sensor could detect the LED, multi-LED configurations were explored.

Mouse movement has seen its initial stages with great difficulty, however, hugely with the help of the hardware implementations, we are now able to start tracking objects with the Pixart sensor. The sensor was successfully interfaced with via SPI communication, and sensor data can now be extracted in real-time. Using this data, a 2D visualization/monitoring tool has been developed to assist in the next steps of development in conjunction with the simulations and theoretical implementations to finally bring mouse movement inputs to the device. An example is shown below of this implementation. The circuit contains four IR-LEDs in parallel with an 100ohm resistor in series with each, all supplied with 2V from the AD2. An example of one of our test setups with dimensions of 75mm x 23 mm is shown below:

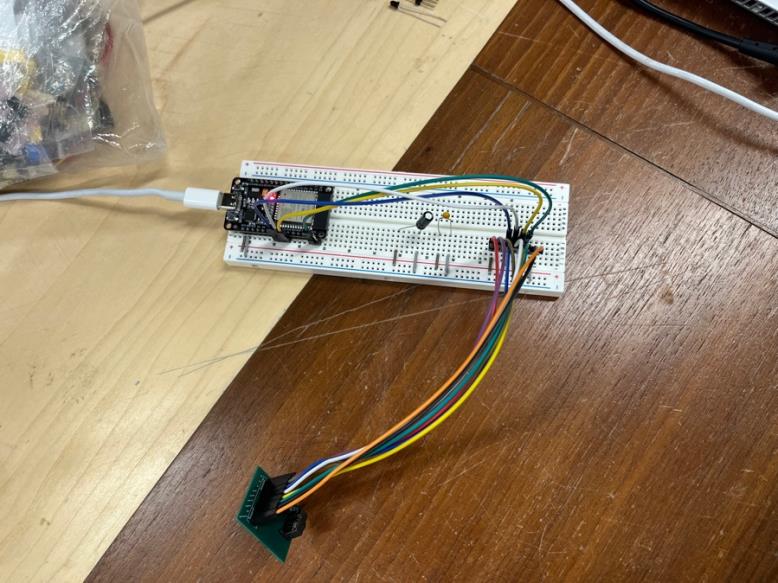
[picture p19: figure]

Figure 17 - PixArt Sensor and ESP32 Setup on Breadboard

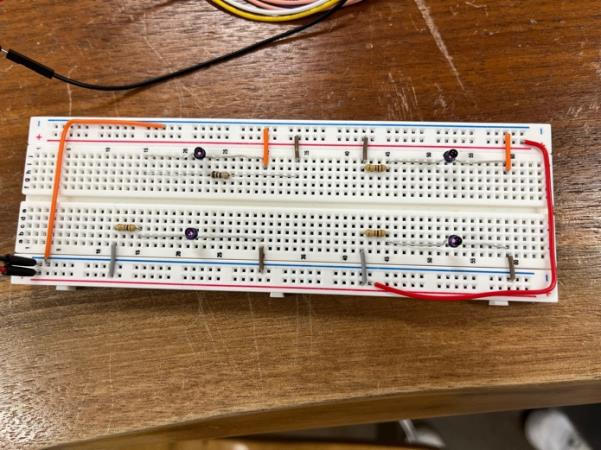
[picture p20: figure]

Figure 18 - Example of LED Circuit Test Setup

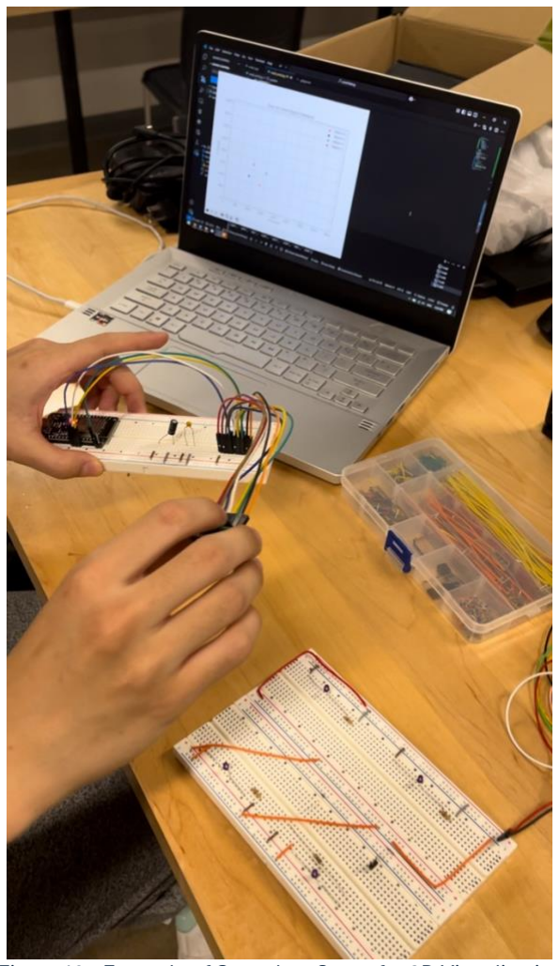
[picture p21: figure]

Figure 19 - Example of Complete Setup for 2D Visualization

For the ESP32 to emulate mouse inputs as an HID, the Espressif IDF toolkit has included examples of BLE usage and several HID demos, which were used in reference to implement our functionality. Note, that there also exists an existing BLE mouse emulation library for the ESP32, that could prove to be very useful for streamlining development and optimizing runtime.

## Mouse Clicking Functions and Haptic Feedback

The mouse clicking and haptic feedback functions are achieved with a coin vibration motor (VCLP1020B002L) and an Inertia Measuring Unit. The selected motor is an LRA (linear resonant actuator), which is used for its compact size and higher efficiency when compared to other haptic motors such as ERM’s (eccentric rotating mass) [12]. Piezoelectric actuators were also considered; however, they were found to be quite expensive, had less options to choose from, and often had abnormal shapes. The Vybronics VCLP1020B002L was selected because it has a low current requirement of 30 mA maximum, meaning it would never exceed the maximum ESP32 GPIO current rating of 40mA. This low power comes at the cost of lower vibration force at only 0.75 Grms, however this is still recognizable to the user, and we determined lower current consumption is of greater importance.

With the motors, we also included the Adafruit DRV2605 drivers, which were then soldered to the motor units to drive the motors. The motor driver has many preset functions which change the feel of the motor vibration. This was attractive to us as it opens the door for more complex feedback signals for a better user experience. The IMU is interfaced onboard the ESP32, where we extract all the sensor data to determine the current state of the device. The clicking function uses the extracted IMU data to determine when to send mouse-click inputs to the host computer.
So far, the IMU has been successfully interfaced via I2C to extract pitch, roll, and angular data from the sensor, and we were also able to mimic mouse inputs to the host computer via Bluetooth on the ESP32 using the BleMouse library.

This was tested using the IMU, Drivers/Motors, and a breadboard. The accelerometer and gyroscope values can be extracted by modifying the provided code from the Adafruit MPU6050 library (please see appendix). Initially, the gyroscope, measuring the rotational velocity along the three axes, was used for the clicking motion. Through trial and error, we noticed that measuring the gyroscope value in the y-axis at a threshold of -/+ 8m/s provided an accurate clicking motion when the wrist was quickly rotated. A right click was performed when the wrist was rotated clockwise and exceeded +8m/s, whereas a left click was performed when the wrist was rotated counter-clockwise when exceeding -8m/s. This value did not capture minimal rotation, which is ideal as we did not want to capture unwanted clicks. However, we noticed that repeated clicks may not be too ergonomic as each click required a quick jolt which may cause strain on the user. Instead, we opted to use the angle, where if the angle (measured by the roll value) exceeds a certain threshold a click is performed. If the angle exceeds -30 degrees, a left click is performed, and if the angle exceeds +30 degrees a right click is performed. If a click is performed, the motor buzzes signifying the user the click was successfully registered. The scrolling motion follows a similar pursuit using the angles captured from the pitch. Calculated using the accelerometer values, the pitch provides an angle range from -90 to +90 degrees. Thus, we set a threshold value that, if exceeded, performed a downward or upward scroll. Again, this value was found using trial and error. We settled at 33 degrees, where an upwards degree was performed if the imu was tilted to exceed +33 degrees, and a downwards scroll was performed if the imu was tiled to exceed -33 degrees. Additionally, we added a calibration function to gather 500 samples and calculate the offsets from the stationary IMU, where this offset was subtracted from values found in the actual simulation.

## Bill of Materials (Matt)

The current Bill of Materials (BOM) can be found below:

Item | Desc | Cost | Tax | Total | Link
ESP32(x2) | x1
| $19.99 | $2.60 | $22.59

ESP 32 ESP-WROOM-32 NodeMCU Development Board, USB Type-C, WLAN WiFi + Bluetooth Dual Core Microcontroller for Arduino IDE, Silicon CP2102 USB Bridge, 2PCS (30 PINS) (https://a.co/d/6Rckx4v)

Motor Unit

Vibration
User
Feedback
x5 | $23.92 | $3.11 | $27.03

https://www.digikey.ca/en/products/detail/vybronics-inc/VCLP1020B002L/10285888 (https://www.digikey.ca/en/products/detail/vybronics-inc/VCLP1020B002L/10285888)

Motor Driver | x2
| | $23.36 | $3.04 | $26.40 | https://www.digikey.ca/en/products/detail/adafruit
| | | | | -industries-
| | | | | llc/2305/5356831?s=N4IgTCBcDaKHAEBGArGA
| | | | | HAWgQZgCwDZ0A5AETgAI4wsAGJcgIQHkBBA
| | | | | JWLIAlmAFAFQCSAYTIBZRn0asyQvgBlpxVgD
| | | | | UweWiAC6AXyA (https://www.digikey.ca/en/products/detail/adafruit-industries-llc/2305/5356831)
Motor Driver
Cable | x4 | $5.60 | $0.73 | $6.33 | https://www.digikey.ca/en/products/detail/adafruit
| | | | | -industries-llc/4209/10230003 (https://www.digikey.ca/en/products/detail/adafruit-industries-llc/4209/10230003)
PixArt Test
PCB | x5 | $21.78 | $2.83 | $24.61 | jlcpcb

Heat Resistant

Tape | x1 | $12.99 | $1.69 | $14.68 | https://www.amazon.ca/dp/B07PTQ16Y8?ref=pp
| | | | | x_yo2ov_dt_b_fed_asin_title&th=1 (https://www.amazon.ca/dp/B07PTQ16Y8?ref=ppx_yo2ov_dt_b_fed_asin_title&th=1)
Flux Paste | x1 | $13.33 | $1.73 | $15.06 | https://www.amazon.ca/dp/B00425FUW2?ref=ppx_yo2ov_dt_b_fed_asin_title&th=1 (https://www.amazon.ca/dp/B00425FUW2?ref=ppx_yo2ov_dt_b_fed_asin_title&th=1)
IR Emitter (Proper Range) | x1 | $5.01 | $0.65 | $5.66 | https://look.ams-S.com/m/4963b77e9d10bec8/original/SFH-4356.pdf (https://look.ams-osram.com/m/4963b77e9d10bec8/original/SFH-4356.pdf)

PixArt
PAJ7025R3
Sample Kit

x5
$104.25

$13.5
5 $117.80

https://www.codico.com/en/paj7025r3-sample-kitcdc (https://www.codico.com/en/paj7025r3-sample-kit-cdc)

## Datasheets (Ryan)

- ESP32: https://www.espressif.com/sites/default/files/documentation/esp32-wroom-32_datasheet_en.pdf (https://www.espressif.com/sites/default/files/documentation/esp32-wroom-32_datasheet_en.pdf)
- VCLP1020B002L Coin Vibration Motor: https://www.vybronics.com/wpcontent/uploads/datasheet-files/Vybronics-VCLP1020B002L-datasheet.pdf (https://www.vybronics.com/wp-content/uploads/datasheet-files/Vybronics-VCLP1020B002L-datasheet.pdf)
- Adafruit DRV2605 Motor Driver: https://cdnlearn.adafruit.com/downloads/pdf/adafruit-drv2605-haptic-controllerbreakout.pdf (https://cdn-learn.adafruit.com/downloads/pdf/adafruit-drv2605-haptic-controller-breakout.pdf)

- MPU6050 IMU: https://compoindia.com/wpcontent/uploads/2021/01/datasheet.pdf (https://compoindia.com/wp-content/uploads/2021/01/datasheet.pdf)
- PixArt PAJ7025R3: *Confidential*
- Infrared LED: https://look.ams-osram.com/m/4963b77e9d10bec8/original/SFH-4356.pdf (https://look.ams-osram.com/m/4963b77e9d10bec8/original/SFH-4356.pdf)

The following are components which have not yet been ordered:
- Potential Battery: https://www.amazon.ca/Rechargeable-Suitable-Electronic-Products-Replacement/dp/B0CKRCXNP9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 fQrLGosQsuE-D065zHPz3rkfCp8UArc1JxNUlKMYPn6rSLQ3MvSJA0t4KM5-4e08J1OSIdO0AneLPXK6us4alcaBHE_lgPtsAxD5HeTC3Bei3dVqBxSNGNefayFPEDr pm3McVZ8DTyPDugPa_Ww1KDqsAeDULA1cgos419kICLzPEQyjdPxH2gOAQghrcD b1NdrFRrcVqLY.lNyNYMLdU74FgF_WuGsXiWqDmGCkLaQjUWIixzw2N34&dib_tag =se&keywords=550+maH+lipoly+battery&qid=1737157342&s=electronics&sprefix= 550+mah+lipoly+battery%2Celectronics%2C109&sr=1-1 (https://www.amazon.ca/Rechargeable-Suitable-Electronic-Products-Replacement/dp/B0CKRCXNP9?s=electronics)
- Firebeetle 2 microcontroller: https://www.dfrobot.com/product-2837.html

## Prediction for Future Progress (George)

As the updated Gantt Chart illustrates, we were impacted by a few unforeseen challenges. These challenges had set us off track with the initial schedule; however, these challenges have been addressed and should bring us back on course. In our current state, we believe we have completed a third of the overall project, where the core elements of our project have been developed, as the purpose, design, and materials are now firmly in place.

The next step is to assemble the hardware and interface it with the software to develop a rudimentary prototype. Providing us with the ability to perform a wide range of tests, from functionality testing to ergonomic testing, over the next few months. We predict the design will be refined multiple times until an optimal design that satisfies all our requirements is found. Additionally, if time allows, we want to develop a GUI to interface with the device, enabling more customization for the user's preferences.

As this project proceeds, we may face more setbacks, such as interfacing the software with the PixArt sensor. To be cautious, we have the IMU as a fallback if significant problems arise with the other sensor.

## Self-Assessment

Performance ratings use the following three levels: excellent, satisfactory, or room for improvement)
George Gill (gillg62)
Tasks and Roles
- Researched and contributed to the general selection of materials.
- Researched different IMUs and helped in the selection for our purpose.
- Assisted in creating conceptual designs for the housing of the sensors and controllers with Matt.
- Developed CAD Models and Assemblies, using Autodesk inventor
- Ensured precision and functionality, while adhering to constraints.
- Assist in 3D printing with Matt.
- Assisted in creating the rough electrical schematic with Luke.
- Used KiCAD to design the final schematic.
- Integrated the IMU, Haptics, and Microcontroller to enable mouse functions such as scrolling and clicking.
- Performed research on different methods of capturing consistent motions.
- Programmed the captured motions into mouse functions.
- Debugging
Performance Assessment
Overall Self-rating: Satisfactory
- I have actively contributed to the development of our project. Assisting in various places but have mostly focused on the layout, interfacing with the IMU and Haptics, and the physical modeling of our design. These contributions have been beneficial to the overall project, bringing us closer to the final solution. However, there is room for improvement by spending more time on these, or future activities. Since my semester has a lighter course load than last term, I plan on spending more time helping the group conclude this project.

## Matthew Yu (yum77)

Tasks and Roles
- Research and develop custom PCB for sensor using KiCad.
- Use KiCad to design schematic diagrams, custom footprints, PCB layouts.
- Redesign custom PCB based on feedback of components needed to be removed or added to PCB.
- Incorporate team feedback to adjust PCB design.
- Revise component selection and layout based on function and size constraints.

- Selection of optimal capacitors, connectors, and cables needed for our systems design.
- Verify compatibility with PCB design and system requirements.
- Reach out to PCB manufacturers to ensure PCB designs can be properly made.
- Research methods for soldering our sensor and other small electrical components.
- Solder sensor to custom PCB and solder any other components needed such as motor driver etc.
- Verify that all solder connections are properly made, the solder joints are of good quality, and no short circuits are present.
- Assist George in prototyping 3d printed housing for sensor and controllers.
- Start 3D printing and assembling physical prototypes along with George.
- Collaborate with team in discussing different ways sensor can be mounted along with input on how to arrange all components to fit in enclosure for lightest and smallest design.
Performance Assessment
Overall Self-rating: Satisfactory
- I put a lot of time and effort into learning how to design PCBs, including using KiCAD for creating custom schematics, footprints, and layouts. I also focused on improving my skills in soldering small SMD components, making sure everything was put together accurately. In addition, I learned how to test and troubleshoot components to quickly identify and fix any issues. Although I successfully completed many important tasks on my own, I see room for improvement in working more closely with the team. I recognize that my focus on independent work limited my opportunities for collaboration with my groupmates. I believe that more active collaboration could have opened up new perspectives and generated better ideas. By sharing knowledge and brainstorming together, the team could have benefited from different points of view, which would have enhanced our overall design and approach. In the future, I plan to make a more concerted effort to engage with my teammates, exchange ideas, and seek feedback throughout the process. I believe that increased teamwork will not only improve my individual contributions but will also lead to more innovative and well-rounded solutions for the project.

## Ryan Xu (xur76)

Tasks and Roles
- Research and acquisition of key components of the project including the microcontroller, IMU, and PixArt sensor.
- Logo Design and overall branding of the project.

- Established communications with PixArt to obtain sample sensors for initial prototyping and development, along with negotiations regarding documentation confidentiality.
- Conceptual development of early-stage system/stack design with the team.
- Assisted Luke in some parts of the development of the python simulations.
- Assisted in the development of the software interfacing process with the Pixart sensor.
- Development of the 2D IR LED object tracking visualization tool.
- Research and early-stage idealizations of user-software UI/UX (Low Priority) Performance Assessment
Overall self-rating: Satisfactory
- Higher productivity near the earlier stages of the project, trailing off in time investments near the time of writing this report. Non-consistent efforts, although meeting demands with good quality in bursts instead of a consistent workflow. Improvements must be made in more consistent work ethics and proactiveness to keep up with and push the speed of development further.

## Luke West (westl5)

Tasks and Roles
- Research and development of Python simulation to model the PixArt sensor and test algorithms for localization of the camera with respect to reference world points
- Testing of communication with physical PixArt sensor over SPI alongside Ryan
- Helped Ryan with test 2D visual implementation of IR LED object tracking
- Visualizations of physical wrist band implementation, using George’s 3D models to develop concept sketches
- Development of initial schematic alongside George ensuring pin for pin correspondence with the components
- Selection of haptic motor driver and motor components
- Selection of IR LEDs
- Selection of more power efficient ESP-32 board option (Firebeetle 2), and investigation into battery types, required power conversion and charging
- Communication with vendors and McMaster to secure additional PixArt sensors
- General support to the team in discussions and meetings involving project design Performance Assessment
Overall self-rating: Satisfactory to Excellent
- There was a lot of time which went into researching the math for the simulation, and cameras in general, it took a while for me to even find the right resources to learn from as there is a lot available online, and it is an area I previously did not know a lot about. The python simulation which I built is sufficient for proof of concept and the visualizations were helpful in determining how our project could work. However, it still does not consider all cases and the algorithm for localization will need to be improved in the actual implementation. Although we were unable to interface with the PixArt sensor until recently, we were able to achieve communication with it using SPI which enabled us to visualize the tracked objects in 2D. I also provided help to groupmates when needed for various aspects of the design, such as the schematic and physical implementation, and set most meeting times for the group at regular intervals throughout the term. In terms of my own effort, I put in spread out short bursts of concentrated work throughout the last term. This work style led to some added stress as I would focus on my other classes then switch to high intensity focus on the capstone project when I started to feel behind. Looking forward to this term, I will be aiming to work more consistently each week rather than in short intense bursts, as I believe this will reduce stress, and improve productivity toward the project.

## References

[1] B. Trzynadlowski, “PixArt PAJ7025R2 6dof Tracking Demo with Arduino and Windows,” GitHub. Accessed: Jan. 03, 2025. [Online]. Available: https://github.com/trzy?tab=repositories&q=PixArt&type=&language=&sort=
[2] “Types of Capacitors: Pros, Cons, & Applications,” Circuit Crush. Accessed: Jan. 16, 2025. [Online]. Available: https://www.circuitcrush.com/types-of-capacitorsapplications/
[3] “What is the Difference Between FFC and FPC? ,” Quadrangle Products. Accessed: Jan. 16, 2025. [Online]. Available: https://www.quadrangleproducts.com/what-isthe-difference-between-ffc-and-fpc/
[4] “FFC vs FPC: Understanding Flexible Cable Technologies,” Newhaven Display International. Accessed: Jan. 16, 2025. [Online]. Available: https://newhavendisplay.com/blog/ffc-vs-fpc-understanding-flexible-cabletechnologies/
[5] A. Brown, “Plated vs Non-Plated PCB Through Holes in PCB Desigs,” epec Engineered Technologies. Accessed: Jan. 16, 2025. [Online]. Available: https://blog.epectec.com/plated-vs-non-plated-pcb-through-holes-in-pcb-designs
[6] “What is a FPC/FFC Connector?,” Omron. Accessed: Jan. 16, 2025. [Online]. Available: https://components.omron.com/eu-en/products/connectors/board-tofpc-connectors/board-to-fpc-connector_features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
[7] “ESP32 Thing Hookup Guide,” Sparkfun. Accessed: Jan. 16, 2025. [Online]. Available: https://learn.sparkfun.com/tutorials/esp32-thing-hookupguide/hardwareoverview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,while%20actively%20trans mitting%20over%20WiFi.
[8] A. N. Balaji, C. Kimber, D. Li, S. Wu, R. Du, and D. Kim, “RetroSphere,” Proc ACM Interact Mob Wearable Ubiquitous Technol, vol. 6, no. 4, pp. 1–36, Dec. 2022, doi: 10.1145/3569479.
[9] “Perspective-n-Point (PnP) pose computation,” OpenCV. Accessed: Jan. 03, 2025. [Online]. Available: https://docs.opencv.org/4.x/d5/d1f/calib3d_solvePnP.html
[10] B. K. P. Horn, “Closed-form solution of absolute orientation using unit quaternions,” Journal of the Optical Society of America A, vol. 4, no. 4, p. 629, Apr. 1987, doi: 10.1364/JOSAA.4.000629.
[11] S. Meers, K. Ward, and I. Piper, “Simple, robust and accurate head-pose tracking using a single camera,” Jan. 2006, [Online]. Available: https://ro.uow.edu.au/articles/conference_contribution/Simple_robust_and_accurate_head-pose_tracking_using_a_single_camera/27792744
[12] “Haptic Technology 101: A Beginner’s Guide to the Different Types of Vibration Motors,” TItan Haptics. Accessed: Jan. 16, 2025. [Online]. Available: https://titanhaptics.com/haptic-technology-101-a-beginners-guide-to-the-differenttypes-of-vibration-motors/

## Appendix

## KiCAD: PixArt Custom PCB Iteration 1

Custom Symbol
Description: The custom symbol was created to represent the PixArt PAJ7025R3 sensor in the schematic. Since the sensor did not have a pre-existing symbol in the KiCad library, it was necessary to design a unique symbol for it.
Purpose: This custom symbol allows for easy integration of the sensor into the schematic, ensuring accurate representation and connectivity in the design.
Details: The symbol includes all relevant pins and is designed to match the pinout of the PixArt sensor.

Custom Schematic
Description: The schematic diagram was designed using the custom symbol and other necessary components. It illustrates the wiring and connections between the PixArt sensor, ESP32 controller, motor units, and other key components.

Purpose: The schematic serves as a blueprint for the entire circuit, ensuring that each component is connected correctly and will function as intended. Schematic will also generate a netlist to ensure correct connections in the PCB editor.

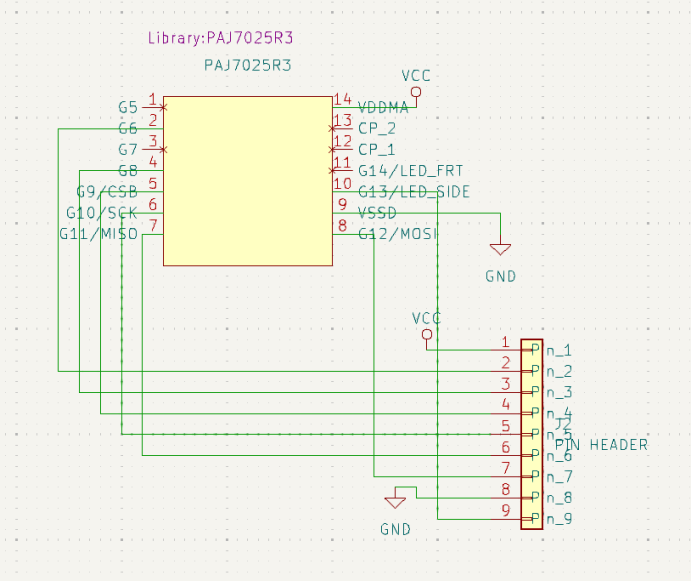
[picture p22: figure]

Custom Footprints
Description: The custom footprint was created for the PixArt PAJ7025R3 sensor, as it did not have a predefined footprint in the KiCad library. This footprint defines the physical layout of the sensor’s pins and pads for the PCB design.

Purpose: The footprint ensures that the PixArt sensor can be accurately placed on the custom PCB, with the appropriate pad sizes and distances.

Details: The footprint includes through-hole pads for the sensor’s connections, with proper alignment and size based on the sensor’s specifications.

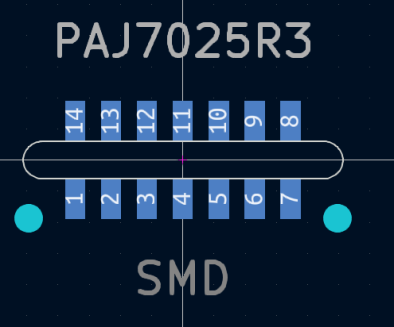
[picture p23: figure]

Description: Custom pin header found online

Purpose: Connect traces to external components such as capacitors and microcontroller.

Details: Taken from KiCad GitHub: https://github.com/KiCad/Connectors_Molex.pretty

Custom PCB

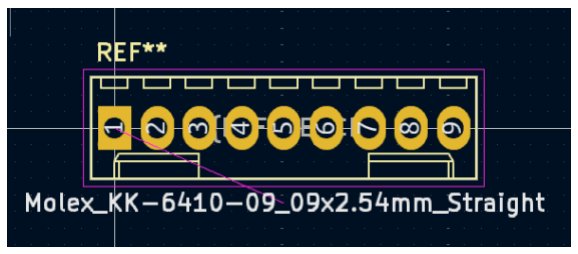
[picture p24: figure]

Description: The final custom PCB design integrates all components, including the PixArt sensor, ESP32, motor drivers, and other critical elements, onto a compact 2-layer board.

Purpose: This PCB physically supports and connects all components, allowing them to work together in the system. It was designed to ensure that the PixArt sensor could interface properly with the rest of the system.

Details: The PCB was designed in KiCad with careful attention to trace routing, component placement, and electrical considerations like power distribution and signal integrity.

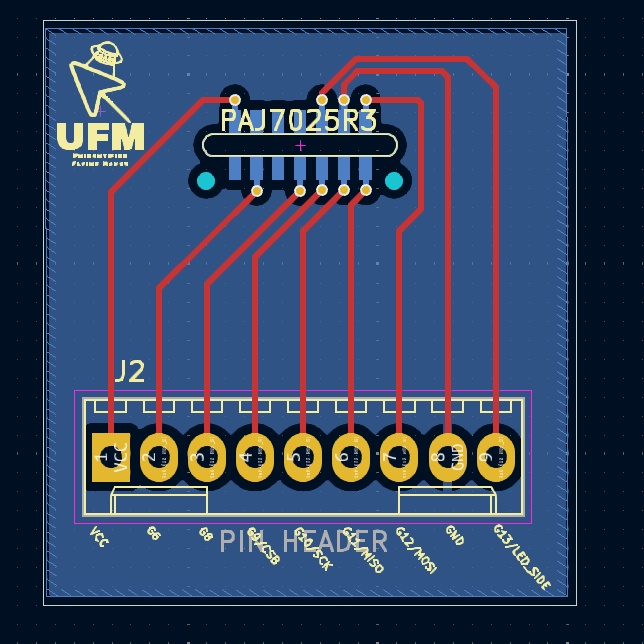
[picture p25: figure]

This section provides a detailed breakdown of the KiCad design process for the custom PCB. By creating the custom symbol, schematic, footprint, and final PCB, we were able to successfully integrate the PixArt PAJ7025R3 sensor into our system, overcoming the challenges posed by the lack of predefined components.

## KiCad: PixArt Custom PCB Iteration 2

Redesign Schematic
Description: The schematic diagram was edited to reduce the number of pins, add the 0.1uF and 10uF capacitors, and change the connector to a 6 pin one.

Added Footprints


Description: Footprints and 3D models provided by Digikey based on part numbers were used to accurately represent electrical components needed to be placed on the capacitor.


0.1 uF Capacitor

10 uF capacitor


FFC connector

Redesign PCB
Description: The final custom PCB design integrates all components needed to be changed or added from the 1st iteration.

## Repositories

Main UFM Repository: https://github.com/westl5/UFM
- All code can be found in the code directory
- All PCB design information can be found in the pcb directory
- Other relevant documents such as datasheets, photos and videos can be found in the docs directory

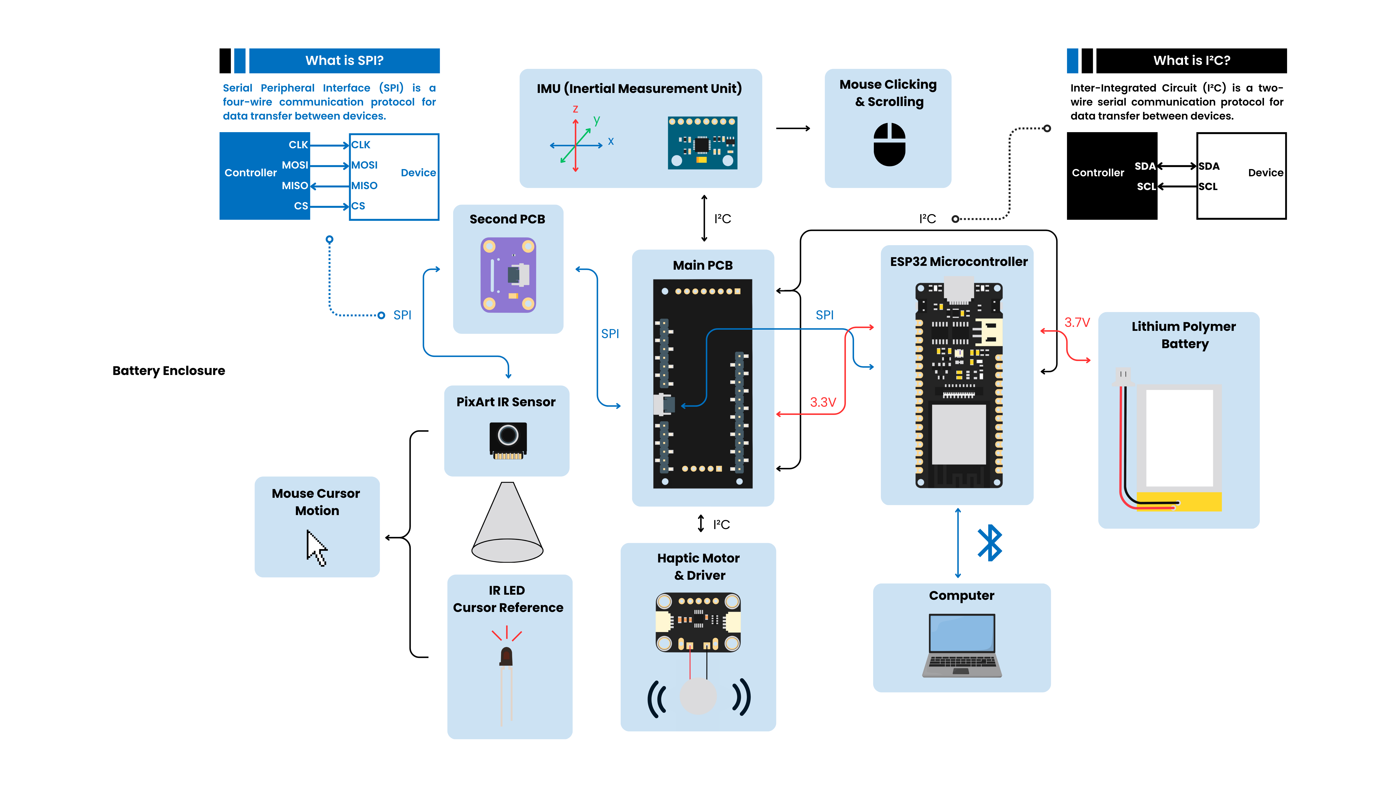
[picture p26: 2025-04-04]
docs/poster/graphics/poster-block-diagram.png

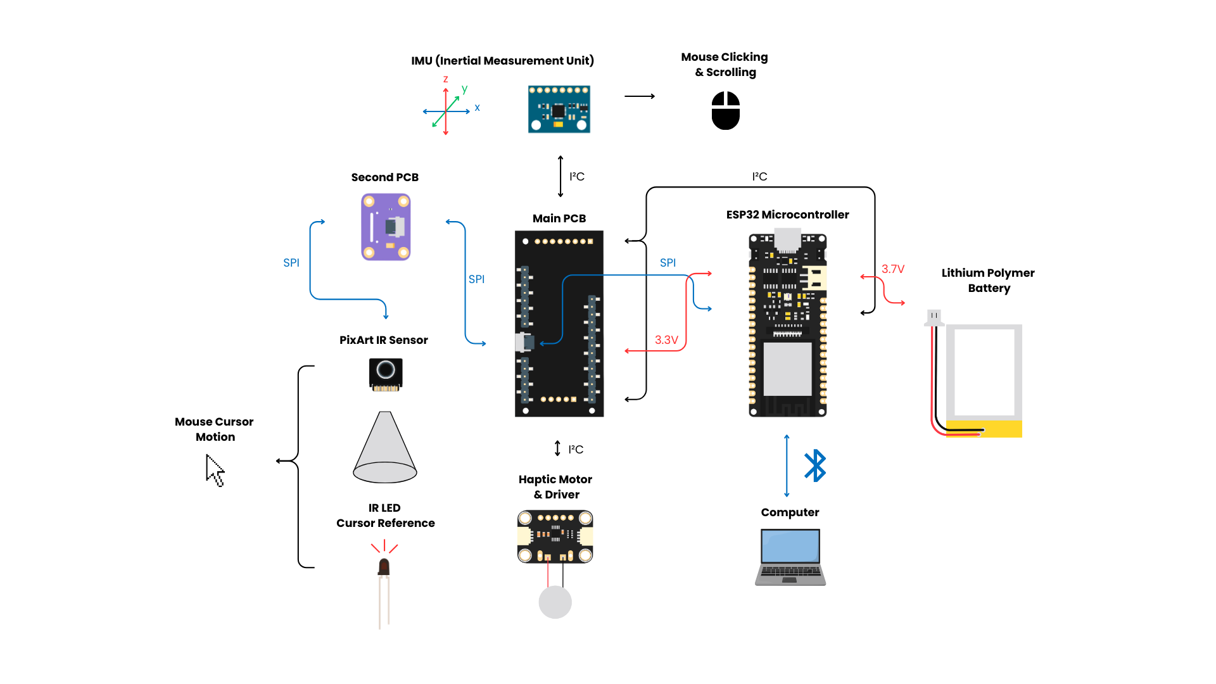
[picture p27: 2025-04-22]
docs/poster/graphics/block-diagram-whitecomponents.png

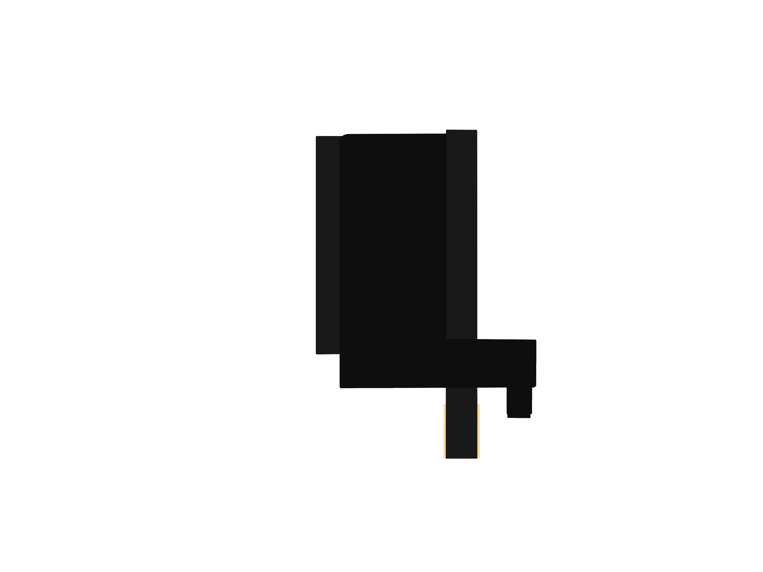
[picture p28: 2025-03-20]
docs/poster/graphics/pixart-sensor-side.png

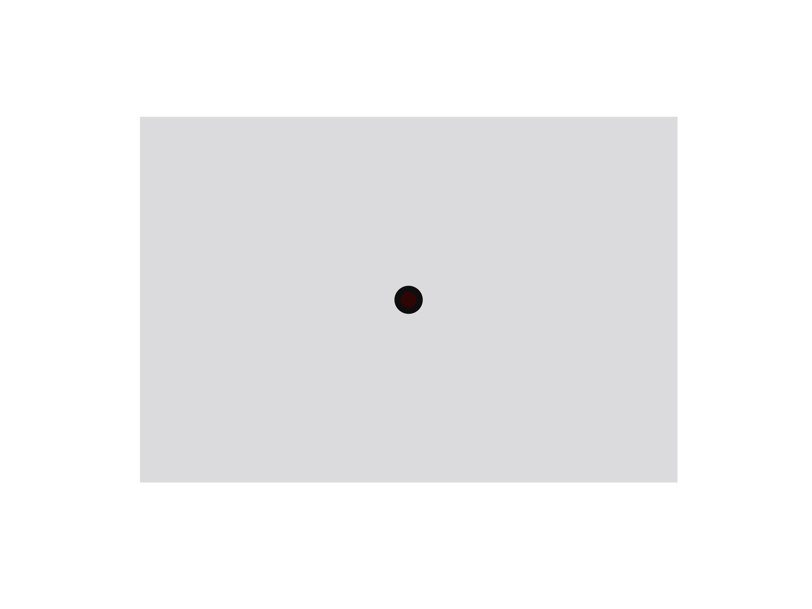
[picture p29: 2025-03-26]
docs/poster/graphics/led-box.png

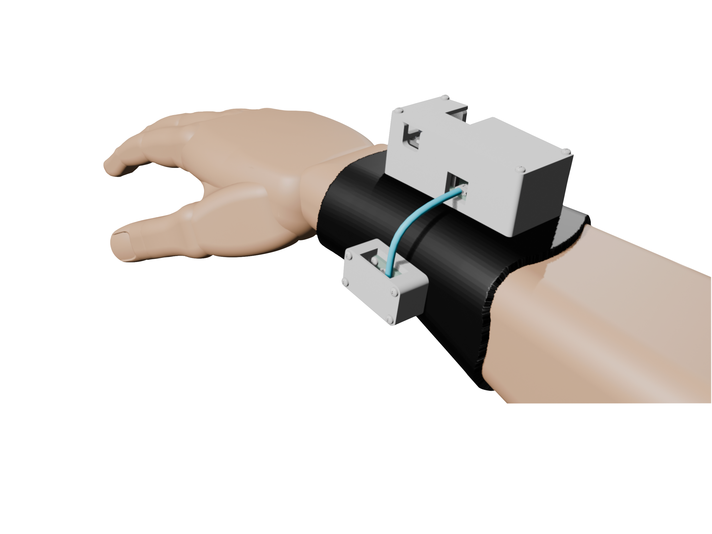
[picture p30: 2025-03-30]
docs/poster/graphics/render-no-bground.png

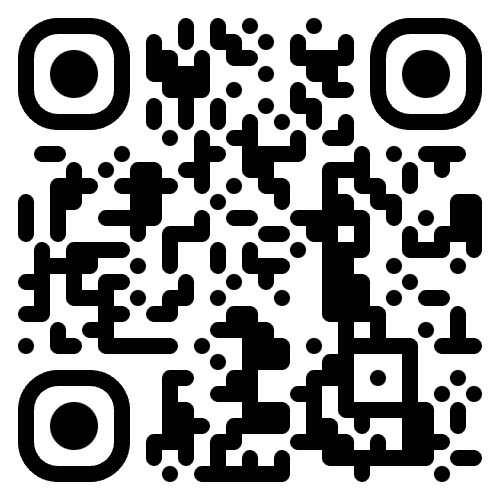
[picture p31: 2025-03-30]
docs/poster/ufm-qr.png

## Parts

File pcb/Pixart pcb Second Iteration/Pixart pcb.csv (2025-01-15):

Reference | Value | Datasheet | Footprint | Qty | DNP
J2 | PIN HEADER | ~ | Library:Molex_KK-6410-09_09x2.54mm_Straight | 1
PAJ7025R3 | ~ |  | Library:PAJ7025R3 | 1

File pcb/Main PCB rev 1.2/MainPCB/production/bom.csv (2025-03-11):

Designator | Footprint | Quantity | Value | LCSC Part #
_3, _2, |  | 3
BOTLEFT1 | PinSocket_1x06_P2.54mm_Vertical_SMD_Pin1Left | 1 | Conn_01x06
FCC1 | CONN_XF3M-0615-1B_OMR | 1 | Conn_01x06
MDVRCONN1 | PinHeader_1x05_P2.54mm_Vertical | 1 | Conn_01x04
MPUCONN1 | PinHeader_1x08_P2.54mm_Vertical | 1 | Conn_01x04
RIGHTSIDE1 | PinSocket_1x14_P2.54mm_Vertical_SMD_Pin1Right | 1 | Conn_01x14
TOPLEFT1 | PinSocket_1x08_P2.54mm_Vertical_SMD_Pin1Left | 1 | Conn_01x08

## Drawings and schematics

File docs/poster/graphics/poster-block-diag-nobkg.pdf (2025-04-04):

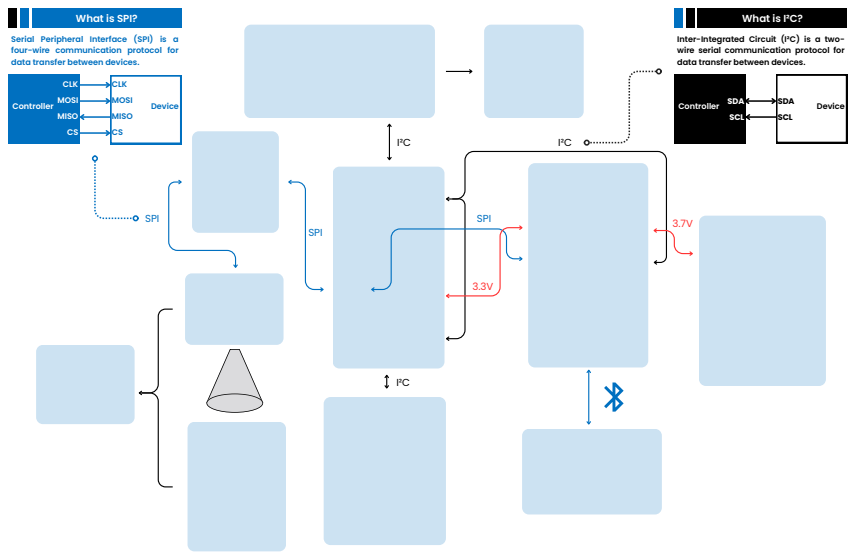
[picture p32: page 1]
CLK MOSI MISO CS; I²C; SPI; Controller; Device; SDA SCL

What is SPI?

What is I²C?

Serial Peripheral Interface (SPI) is a
four-wire communication protocol for
data transfer between devices.

Inter-Integrated Circuit (I²C) is a two-
wire serial communication protocol for

SPI

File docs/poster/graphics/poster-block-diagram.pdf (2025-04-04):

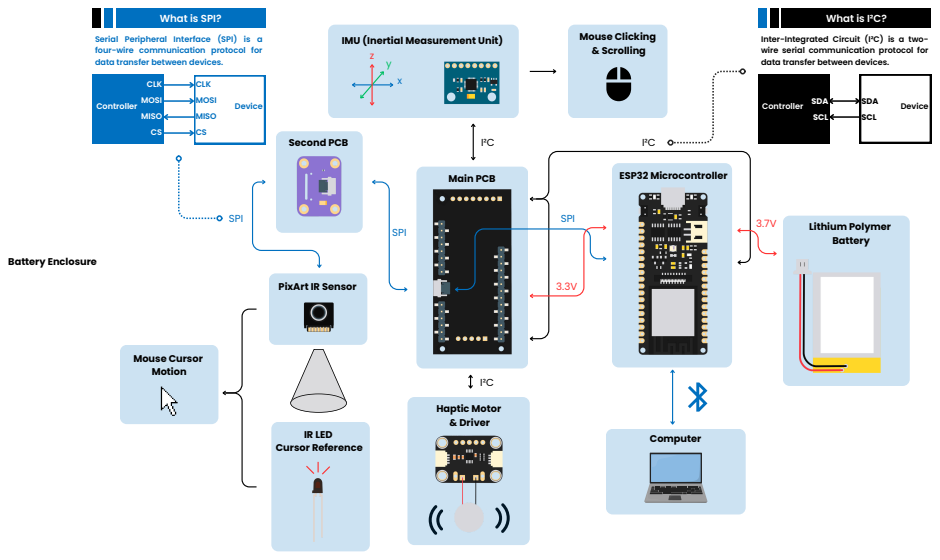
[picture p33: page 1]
CLK MOSI MISO CS; SPI; I²C; IMU (Inertial Measurement Unit); Main PCB; Haptic Motor & Driver; Computer; Lithium Polymer Battery; ESP32 Microcontroller; IR LED Cursor Reference; Mouse Clicking & Scrolling; Mouse Cursor Motion; Second PCB; Controller; Device; SDA SCL; Battery Enclosure

What is SPI?

What is I²C?

Serial Peripheral Interface (SPI) is a
four-wire communication protocol for
data transfer between devices.

Inter-Integrated Circuit (I²C) is a two-
wire serial communication protocol for

PixArt IR Sensor

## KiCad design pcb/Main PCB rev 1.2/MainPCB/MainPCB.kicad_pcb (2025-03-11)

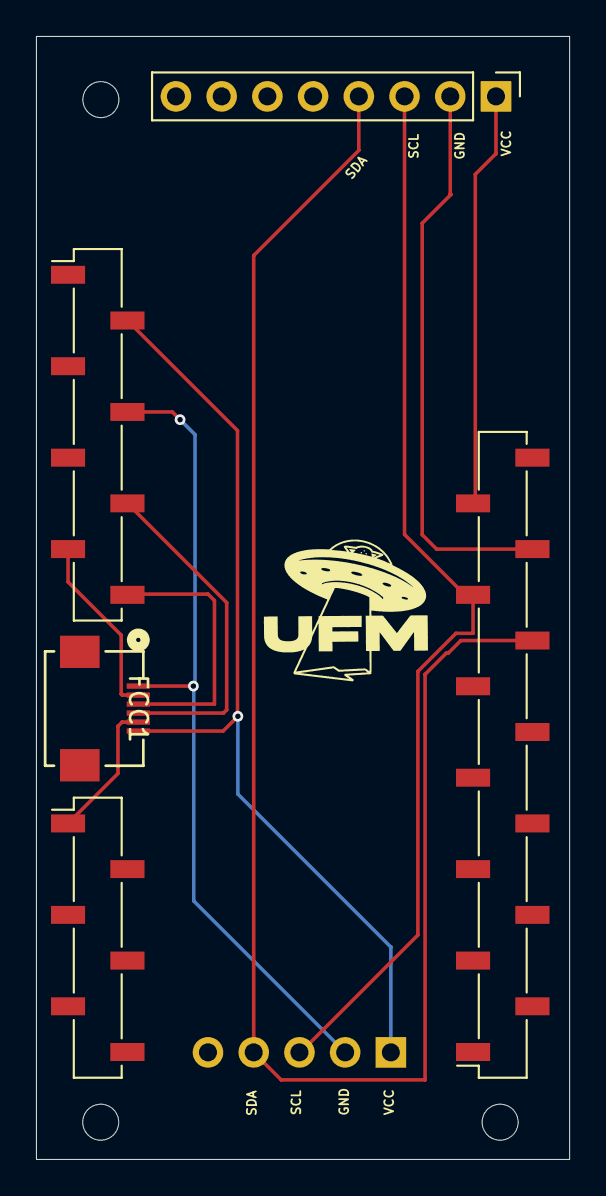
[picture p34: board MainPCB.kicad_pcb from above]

Board: 2 copper layers, 29.6 x 62.4 mm, 6 parts (1 on the bottom side), 8 nets.

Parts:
BotLeft1: Conn_01x06; PinSocket_1x06_P2.54mm_Vertical_SMD_Pin1Left
FCC1: Conn_01x06; CONN_XF3M-0615-1B_OMR
MDVRCONN1: Conn_01x04; PinHeader_1x05_P2.54mm_Vertical
MPUCONN1: Conn_01x04; PinHeader_1x08_P2.54mm_Vertical
RightSide1: Conn_01x14; PinSocket_1x14_P2.54mm_Vertical_SMD_Pin1Right
Topleft1: Conn_01x08; PinSocket_1x08_P2.54mm_Vertical_SMD_Pin1Left

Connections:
/CSB: BotLeft1.1, FCC1.5
/GND: FCC1.1, MDVRCONN1.2, MPUCONN1.2, RightSide1.12, Topleft1.4
/MISO: FCC1.3, Topleft1.8
/MOSI: FCC1.2, Topleft1.7
/SCK: FCC1.4, Topleft1.6
/SCL: MDVRCONN1.3, MPUCONN1.3, RightSide1.11
/SDA: MDVRCONN1.4, MPUCONN1.4, RightSide1.10
/VCC: FCC1.6, MDVRCONN1.1, MPUCONN1.1, RightSide1.13, Topleft1.2

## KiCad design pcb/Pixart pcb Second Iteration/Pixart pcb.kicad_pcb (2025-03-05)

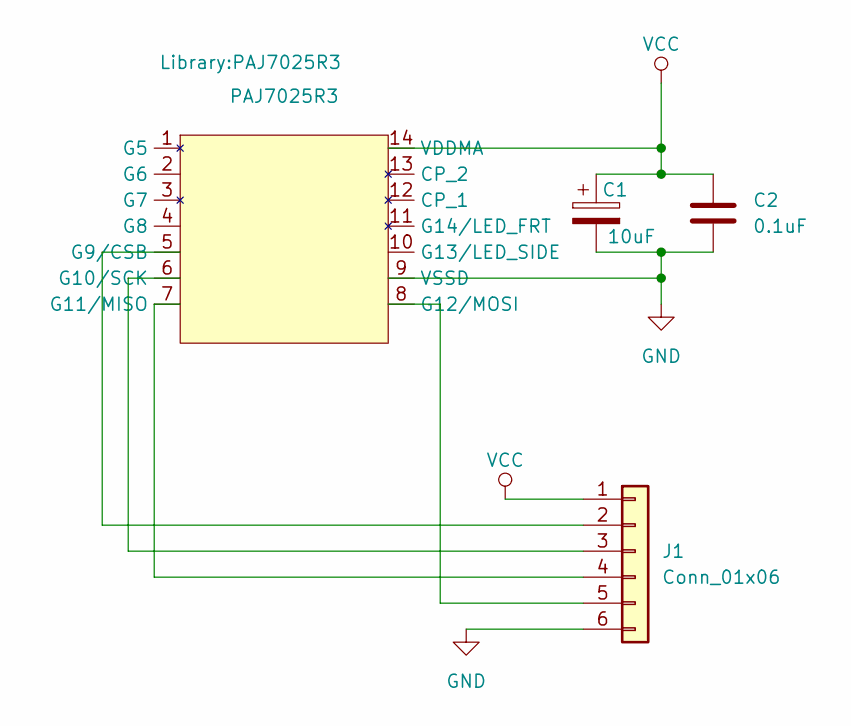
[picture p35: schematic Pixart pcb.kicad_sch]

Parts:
C1: 10uF; TAJA106K016RNJ 10uF
C2: 0.1uF; GRM155R71C104KA88D 0.1uF
J1: Conn_01x06; Molex_KK-6410-06_06x2.54mm_Straight
PAJ7025R3: PAJ7025R3

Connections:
GND: C1.2, C2.2, J1.6, PAJ7025R3.9 (VSSD)
unnamed: J1.2, PAJ7025R3.5 (G9/CSB)
unnamed: J1.3, PAJ7025R3.6 (G10/SCK)
unnamed: J1.4, PAJ7025R3.7 (G11/MISO)
unnamed: J1.5, PAJ7025R3.8 (G12/MOSI)
VCC: C1.1, C2.1, J1.1, PAJ7025R3.14 (VDDMA)

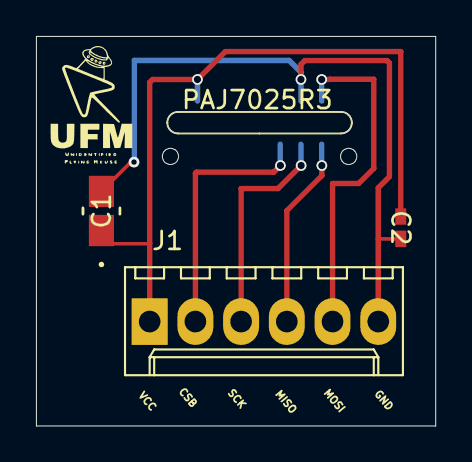
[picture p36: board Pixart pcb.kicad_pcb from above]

Board: 2 copper layers, 22.2 x 21.6 mm, 4 parts (0 on the bottom side), 6 nets.

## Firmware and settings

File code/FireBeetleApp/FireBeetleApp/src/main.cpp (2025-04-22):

/*
EE40I6 Capstone Project - UFM - Group 10
members: westl5, gillg62, xur76, yum77

This code is based on code from Bart Trzynadlowski at the following link:
https://github.com/trzy/PixArt

We are using this as a test to interface between the PixArt PAJ7025R3 Sensor and the ESP-32 board.


  +-------------------+
  |     PAJ7025R3     |
  |                   |
  |      ooooooo      |
  |                   |
  |                   |
  |   -------------   |
  | o o o o o o o o o |
  +-|-|-|-|-|-|-|-|-|-+
    | | | | | | | | |
    | | | | | | | | (OG) G13/LED_SIDE
    | | | | | | | (BK) GND
    | | | | | | (GN) G12/MOSI
    | | | | | (YE) G11/MISO
    | | | | (WH) G10/SCK
    | | | (BL) G9/CSB
    | | (BN) G8/VSYNCH
    | (VT) G6/FOD_TRIGGER
    (RD) VDDMA/VCC
 
  VDDMA          -> 3v3
  G9/CSB         ->
  G10/SCK        ->
  G11/MISO       ->
  G12/MOSI       ->
  GND            -> GND

  IR LEDs: OSRAM SF 4356, 860nm wavelength, which is within the PixArt PAJ7025R3's detection range of 800-900nm 
*/

 #include <cstdio>
 #include <cstring>
 #include <Arduino.h>
 #include <SPI.h> 

 #include <BleMouse.h>
 #include <Adafruit_MPU6050.h>
 #include <wire.h>
 #include <Adafruit_DRV2605.h>

 BleMouse bleMouse("UFM-01"); //create bleMouse object
 Adafruit_MPU6050 mpu;
 Adafruit_DRV2605 drv;




 #define SPI_CLK_SPEED 14000000 //14MHz is max value for PixArt sensor
 #define DEBUG_IMAGE 0x00
   /*
   DSP Settings; test images
   write one of following image_num values to 0x2b register in bank 0x01 to set test image
 
   0x00: test image off
   0x05: 16 fixed objects
   0x06: 4 fixed objects
   0x07: circling moving objects
   0x0b: 4 fixed 1 pixel boundary objects
   */
 
 static unsigned s_frame_period_micros;
 struct PA_object
 {
   uint16_t area; 
   uint16_t cx;
   uint16_t cy;
   uint8_t average_brightness;
   uint8_t max_brightness;
   uint8_t range;
   uint8_t radius;
   uint8_t boundary_left;
   uint8_t boundary_right;
   uint8_t boundary_up;
   uint8_t boundary_down;
   uint8_t aspect_ratio;
   uint8_t vx;
   uint8_t vy;
   
   //renders boundary information into a symbol based visualization of the object
   void render(char *output, int pitch, char symbol)
   {
     int lx = min(97, (int) boundary_left);
     int rx = min(97, (int) boundary_right);
     int uy = min(97, (int) boundary_up);
     int dy = min(97, (int) boundary_down);
     Serial.print(lx,DEC);Serial.print(",");Serial.print(rx,DEC);Serial.print(",");Serial.print(uy,DEC);Serial.print(",");Serial.print(dy,DEC);Serial.print("\n");
     for (int y = uy; y <= dy; y++)
     {
       for (int x = lx; x <= rx; x++)
       {
         output[y * pitch + x] = symbol;
       }
     }
   }
   //prints relevant object information over serial
   void print()
   {
     char buffer[1024];
     char *ptr = buffer;
     ptr += sprintf(ptr, "center          = (%d,%d)\n", cx, cy);
     ptr += sprintf(ptr, "area            = %d\n", area);
     ptr += sprintf(ptr, "avg. brightness = %d\n", average_brightness);
     ptr += sprintf(ptr, "max brightness  = %d\n", max_brightness);
     ptr += sprintf(ptr, "range           = %d\n", range);
     ptr += sprintf(ptr, "radius          = %d\n", radius);
     ptr += sprintf(ptr, "boundary        = (%d,%d,%d,%d)\n", boundary_left, boundary_right, boundary_up, boundary_down);
     ptr += sprintf(ptr, "aspect          = %d\n", aspect_ratio);
     ptr += sprintf(ptr, "vx              = %d\n", vx);
     ptr += sprintf(ptr, "vy              = %d\n", vy);
     Serial.print(buffer);
   }
   //loads object data from sensor into PA_object struct
   void load(const uint8_t *data, int format)
   {
     memset(this, 0, sizeof(this));
 
     // Formats 1-4
     area = data[0] | ((data[1] & 0x3f) << 8);
     cx = data[2] | ((data[3] & 0x0f) << 8);
     cy = data[4] | ((data[5] & 0x0f) << 8);
 
     // Format 1, 3
     if (format == 1 || format == 3)
     {
       average_brightness = data[6];
       max_brightness = data[7];
       range = data[8] >> 4;
       radius = data[8] & 0xf;
     }
 
     if (format == 1 || format == 4)
     {
       int offset = format == 4 ? 3 : 0;
       boundary_left = data[9 - offset] & 0x7f;
       boundary_right = data[10 - offset] & 0x7f;
       boundary_up = data[11 - offset] & 0x7f;
       boundary_down = data[12 - offset] & 0x7f;
       aspect_ratio = data[13 - offset];
       vx = data[14 - offset];
       vy = data[15 - offset];
     }
   }
 
   PA_object(const uint8_t *data, int format)
   {
     load(data, format);
   }
 
   PA_object()
   {
   }
 };
 
 //Writes data to specified register using SPI
 void PA_write(uint8_t reg, uint8_t data)
 {
   SPI.transfer(0x00);     // bit 7 = write (0), bits 6-0 = single byte (0)
   SPI.transfer(reg);
   SPI.transfer(data);
 }
 
 //Reads data from specified register using SPI
 uint8_t PA_read(uint8_t reg)
 {
   SPI.transfer(0x80);     // bit 7 = read (1), bits 6-0 = single byte (0)
   SPI.transfer(reg);
   return SPI.transfer(0);
 }
 
 //Burst reads data from specified register using SPI, and stores it in buffer
 void PA_burst_read(uint8_t reg_base, uint8_t buffer[], uint16_t num_bytes)
 {
   SPI.transfer(0x81); //0b 1000 0001 bit 7 = read (1), bits 6-0 = multyple bytes (1)
   SPI.transfer(reg_base); //specify register to start reading from
   for (uint16_t i = 0; i < num_bytes; i++) // read num_bytes of data
   {
     buffer[i] = SPI.transfer(0);
   }
 }
 
 double PA_get_frame_period_microseconds()
 {
   PA_write(0xef, 0x0c); // bank C
   uint32_t cmd_frame_period = PA_read(0x07);
   cmd_frame_period |= PA_read(0x08) << 8;
   cmd_frame_period |= PA_read(0x09) << 16;
   double frame_period_100ns = (double) cmd_frame_period;
   double frame_period_millis = frame_period_100ns * 1e-1; // 100 ns -> us
   return frame_period_millis;
 }
 
 double PA_get_frame_period_milliseconds()
 {
   return 1e-3 * PA_get_frame_period_microseconds();
 }
 
 //Prints settings of the sensor
 void PA_print_settings()
 {
     // Register bank 0
     PA_write(0xef, 0);
     uint16_t product_id = (uint16_t(PA_read(0x03)) << 8) | PA_read(0x02);
     uint16_t dsp_area_max_threshold = (PA_read(0x0c) << 8) | PA_read(0x0b);
     uint8_t dsp_noise_threshold = PA_read(0x0f);
     uint8_t dsp_orientation_ratio = PA_read(0x10);
     uint8_t dsp_orientation_factor = PA_read(0x11);
     uint8_t dsp_max_object_num = PA_read(0x19);
 
     // Register bank 1
     PA_write(0xef, 1);
     uint8_t sensor_gain_1 = PA_read(0x05);
     uint8_t sensor_gain_2 = PA_read(0x06);
     uint16_t sensor_exposure_length = (PA_read(0x0f) << 8) | PA_read(0x0e);
 
     // Register bank C
     PA_write(0xef, 0x0c);
     uint16_t cmd_scale_resolution_x = (PA_read(0x61) << 8) | PA_read(0x60);
     uint16_t cmd_scale_resolution_y = (PA_read(0x63) << 8) | PA_read(0x62);
 
     // Reset back to bank 0
     PA_write(0xef, 0);
 
     // Print everything
     char buffer[2048];
     char *ptr = buffer;
     ptr += sprintf(ptr, "PAJ7025R3 Settings\n");
     ptr += sprintf(ptr, "------------------\n");
     ptr += sprintf(ptr, "Product ID                    = %04x\n", product_id);
     ptr += sprintf(ptr, "DSP area max threshold        = %04x\n", dsp_area_max_threshold);
     ptr += sprintf(ptr, "DSP noise threshold           = %02x\n", dsp_noise_threshold);
     ptr += sprintf(ptr, "DSP orientation ratio         = %02x\n", dsp_orientation_ratio);
     ptr += sprintf(ptr, "DSP orientation factor        = %02x\n", dsp_orientation_factor);
     ptr += sprintf(ptr, "DSP maximum number of objects = %02x\n", dsp_max_object_num);
     ptr += sprintf(ptr, "Sensor gain 1                 = %02x\n", sensor_gain_1);
     ptr += sprintf(ptr, "Sensor gain 2                 = %02x\n", sensor_gain_2);
     ptr += sprintf(ptr, "Sensor exposure length        = %04x\n", sensor_exposure_length);
     ptr += sprintf(ptr, "Scale resolution X            = %04x\n", cmd_scale_resolution_x);
     ptr += sprintf(ptr, "Scale resolution Y            = %04x\n", cmd_scale_resolution_y);
     ptr += sprintf(ptr, "Frame period                  = %1.4f ms\n", PA_get_frame_period_milliseconds());
     Serial.print(buffer);
 }
 //Performs initial settings sequence as per PAJ7025R3 datasheet
 void PA_load_initial_settings()
 {
   //0xef is the bank select register, holds value bank_no[7:0]
   //switch to bank 0x00
   PA_write(0xef, 0x00); 
   PA_write(0xdc, 0x00); //as per initial settings sequence, register purpose not specified in datasheet
   PA_write(0xfb, 0x04); //as per initial settings sequence, register purpose not specified in datasheet
 
   //switch to bank 0x00
   PA_write(0xef, 0x00); 
   PA_write(0x2f, 0x05); //set cmd_manual_powercontrol_sensor_on to 1 at bits 0 and 2 (power on sensor)
   PA_write(0x30, 0x00); //make manual power control effective by first setting update flag 0
   PA_write(0x30, 0x01); //then set flag to 1
   PA_write(0x1f, 0x00); //as per initial settings sequence, register purpose not specified in datasheet
   
   //switch to bank 0x01
   PA_write(0xef, 0x01); 
   PA_write(0x2d, 0x00); 
 
   //switch to bank 0x0C
   PA_write(0xef, 0x0c); 
   PA_write(0x64, 0x00); //purpose of registers 0x12,0x13 and 0x64-0x72 not specified in datasheet
   PA_write(0x65, 0x00);
   PA_write(0x66, 0x00);
   PA_write(0x67, 0x00);
   PA_write(0x68, 0x00);
   PA_write(0x69, 0x00);
   PA_write(0x6a, 0x00);
   PA_write(0x6b, 0x00);
   PA_write(0x6c, 0x00);
   PA_write(0x71, 0x00);
   PA_write(0x72, 0x00);
   PA_write(0x12, 0x00);
   PA_write(0x13, 0x00); 
 
   PA_write(0xef, 0x00);  //switch to bank 0x00
   PA_write(0x01, 0x01);  // APPLY_COMMAND_2 (bank0_synch_updated_flag = 1)
 }
 //Set frame rate for settings for the sensor, only applicable in STREAM mode
 void PA_set_frame_rate(double hz)
 {
   //Default frame rate is 200.88 Hz
   //Default cmd_frame_period is 0x00C274 = 49780, 100ns*49780 = 4.978 ms
   double period = 1.0 / hz;
   double period_100ns = 1e7 * period; //convert period to 100ns units
   uint32_t cmd_frame_period = (uint32_t) round(period_100ns);
 
   //cmd_frame period is a 20-bit value [19:0] from registers 0x07, 0x08, 0x09 in bank 0x0C
   PA_write(0xef, 0x0c); // switch to bank 0x0C
   PA_write(0x07, cmd_frame_period & 0xff); //cmd_frame_period [7:0] stored in 0x07
   PA_write(0x08, (cmd_frame_period >> 8) & 0xff); //cmd_frame_period [15:8] stored in 0x08
   PA_write(0x09, (cmd_frame_period >> 16) & 0xf); //cmd_frame_period [19:16] stored in 0x09
 
   char buffer[2048];
   sprintf(buffer, "cmd_frame_period = 0x%05x\n", cmd_frame_period);
   Serial.print(buffer); 
 }
 
 void PA_set_sensor_exposure_time(double time)
 {
   //Minimum allowable exposure time = 20us 
   //Maximum allowable exposure time = frame_period - 2.7ms
   double exposure_time_200ns = time / 200e-9;
   uint32_t b_expo = (unsigned int) round(exposure_time_200ns);
 
   PA_write(0xef, 0x0c); //switch to bank 0x0C
   //b_expo is a 16 bit value [15:0] stored in registers 0x0F, 0x10
   PA_write(0x0f, b_expo & 0xff); //b_expo [7:0] stored in 0x0F
   PA_write(0x10, (b_expo >> 8) & 0xff); //b_expo [15:8] stored in 0x10
   PA_write(0xef, 0x01); // APPLY_COMMAND_1 (switch to reigster bank 0x01)
   PA_write(0x01, 0x01); // APPLY_COMMAND_2 (bank1_synch_updated_flag)
 
   //NOTE: new exposure settings will take effect 2 frames after setting the update flag 
 
   char buffer[2048];
   sprintf(buffer, "b_expo = 0x%04x\n", b_expo);
   Serial.print(buffer);
 }
 
 void PA_set_sensor_gain(uint8_t b_global, uint8_t b_ggh)
 {
   /*
   gain = (1 + b_global/16) * H
 
   | b_ggh | 0 | 2 | 3 |
   | H     | 1 | 2 | 4 |
 
   Sensor Gain Table (from datasheet)
   +------------------------------------------+
   |     Gain      |          b_ggh           |
   |               |  0x00  |  0x02  |  0x03  |
   +------------------------------------------+
   |          0x00 | 1.0000 | 2.0000 | 4.0000 |
   |          0x01 | 1.0625 | 2.1250 | 4.2500 |
   |          0x02 | 1.1250 | 2.2500 | 4.5000 |
   |          0x03 | 1.1875 | 2.3750 | 4.7500 |
   |          0x04 | 1.2500 | 2.5000 | 5.0000 |
   |          0x05 | 1.3125 | 2.6250 | 5.2500 |
   |          0x06 | 1.3750 | 2.7500 | 5.5000 |
   |          0x07 | 1.4375 | 2.8750 | 5.7500 |
   | b_global 0x08 | 1.5000 | 3.0000 | 6.0000 |
   |          0x09 | 1.5625 | 3.1250 | 6.2500 |
   |          0x0a | 1.6250 | 3.2500 | 6.5000 |
   |          0x0b | 1.6875 | 3.3750 | 6.7500 |
   |          0x0c | 1.7500 | 3.5000 | 7.0000 |
   |          0x0d | 1.8125 | 3.6250 | 7.2500 |
   |          0x0e | 1.8750 | 3.7500 | 7.5000 |
   |          0x0f | 1.9375 | 3.8750 | 7.7500 |
   |          0x10 | 2.0000 | 4.0000 | 8.0000 |
   +------------------------------------------+
   */
  
   PA_write(0xef, 0x0c); // switch to bank 0x0C
   PA_write(0x0b, b_global & 0x1f); // b_global [4:0] stored in 0x0B
   PA_write(0x0c, b_ggh & 3);  // b_ggh [1:0] stored in 0x0C
   PA_write(0xef, 0x01); // APPLY_COMMAND_1 (switch to register bank 0x01)
   PA_write(0x01, 0x01); // APPLY_COMMAND_2 (bank1_synch_updated_flag)
 
   //NOTE: new exposure settings will take effect 2 frames after setting the update flag 
 }
 
 void PA_set_debug_image(uint8_t image_num)
 {
   /*
   DSP Settings; test images
   write one of following image_num values to 0x2b register in bank 0x01 to set test image
 
   0x00: test image off
   0x05: 16 fixed objects
   0x06: 4 fixed objects
   0x07: circling moving objects
   0x0b: 4 fixed 1 pixel boundary objects
   */
 
   PA_write(0xef, 0x01); // bank 1
   PA_write(0x2b, image_num);
   PA_write(0xef, 0x01); // APPLY_COMMAND_1 (needed?)
   PA_write(0x01, 0x01); // APPLY_COMMAND_2 (...)
 }
 
 void PA_read_report(PA_object objs[16], int format)
 {
   uint8_t report[256];
   int num_bytes = 256;
   uint8_t format_code = 5;
 
   switch (format)
   {
     default:
       break;
     case 1: // format 1: 256-byte, register bank 0x05, Address 0x00-0xFF
       num_bytes = 256;
       format_code = 5;
       break;
     case 2: // format 2: 96-byte, register bank 0x09, Address 0x00-0x5F
       num_bytes = 96;
       format_code = 9;
       break;
     case 3: // format 3: 144-byte, register bank 0x0A, Address 0x00-0x8F
       num_bytes = 144;
       format_code = 10;
       break;
     case 4: // format 4: 208-byte, register bank 0x0B, Address 0x00-0xCF
       num_bytes = 208;
       format_code = 11;
       break;
   }
 
   PA_write(0xef, format_code); //switch to register bank with desired data format
   PA_burst_read(0, report, num_bytes); //read all sensor data into report buffer to get object data
 
   int label_size = num_bytes / 16;
   for (int i = 0; i < 16; i++)
   {
     objs[i].load(&report[i * label_size], format);
   }
 }
 
 void PA_init()
 {
 
   // SPI begin
   SPI.beginTransaction(SPISettings(SPI_CLK_SPEED, LSBFIRST, SPI_MODE3));
 
   // Set up
   digitalWrite(SS, 0);  // chip select pulled low to start communication with sensor
   PA_load_initial_settings(); //load initial settings as per datasheet sequence
 
   //PA_set_frame_rate(30);
   //PA_set_frame_rate(200.88);
   //PA_set_sensor_exposure_time(1.6384e-3);
   //PA_set_sensor_gain(0x10, 0);
 
   PA_set_debug_image(DEBUG_IMAGE); //turn off debug image mode 
   // PA_print_settings(); //print settings to serial monitor
   s_frame_period_micros = (unsigned) PA_get_frame_period_microseconds(); //get frame period in microseconds
 
   digitalWrite(SS, 1); //deassert chip select to end SPI transaction
 
  //  // Read first frame from sensor
  //  for (int i = 0; i < 1; i++)
  //  {
  //    delayMicroseconds(s_frame_period_micros);
  //  }
   digitalWrite(SS, 0); //CSB low to start SPI transaction
   PA_object objs[16]; //create object array to store object data
   PA_read_report(objs, 1); //read object data into object array
   digitalWrite(SS, 1); //CSB high to end SPI transaction
 
   // SPI end
   //SPI.endTransaction();
 
   // Print detected objects from the first frame read
   // for (int i = 0; i < 16; i++)
   // {
   //   Serial.print("Object ");
   //   Serial.print(i, DEC);
   //   Serial.print("\n");
   //   Serial.print("--------");
   //   Serial.print(i >= 10 ? "-\n" : "\n");
   //   objs[i].print();
   // }
 
   // Render image of detected objects in first frame
   // char *image = (char *) malloc((98 + 1) * 98 + 1);
   // memset(image, '.', 99 * 98);
   // for (int y = 0; y < 98; y++)
   // {
   //   image[y * 99 + 98] = '\n';
   // }
   // image[99 * 98] = 0;
 
   // for (int i = 0; i < 16; i++)
   // {
   //   char symbol = i < 10 ? ('0' + i) : ('a' + i - 10);
   //   objs[i].render(image, 99, symbol);
   // }
   // Serial.print("Image:\n");
   // Serial.print(image);
   // free(image);
 }




// ------------------------------------------------------------------------------------------------------------------------------------
// MAIN
// ------------------------------------------------------------------------------------------------------------------------------------
int res_x = 1920;
int res_y = 1080;

int last_x_pos =0;
int last_y_pos =0;
int static_cursor_frame_count = 0;
int click_mode_frame_count = 0;
bool click_mode = false;

int sensitivity = 2.0;
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
void loop() {

  processSerialCommands(); // Process incoming serial commands
  /* CLICK MODE*/
  if(click_mode == true){
    /* Get new IMU events with the readings */
    sensors_event_t a, g, temp;
    mpu.getEvent(&a, &g, &temp);

    /* IMU variables */
    int calx, caly, calz;
    float acc_x, acc_y, acc_z, gyro_x, gyro_y, gyro_z;
    acc_x = a.acceleration.x - 0; //Store Acceleration for each Axis
    acc_y = a.acceleration.y - 0;
    acc_z = a.acceleration.z;
    gyro_x = g.gyro.x; //Store Gyro Values
    gyro_y = g.gyro.y;
    gyro_z = g.gyro.z;
    
    /* pitch and roll */
    float roll_a, pitch_a;
    roll_a = atan2(acc_x,sqrt((acc_y*acc_y)+(acc_z*acc_z))) * 180/PI; //Roll Calc
    pitch_a = atan2(acc_y,sqrt((acc_x*acc_x)+(acc_z*acc_z))) * 180/PI; //Pitch Calc

    /* check for clicks*/
    if ((pitch_a > 50) && (pitch_a < 80)){ // Left click
      // Serial.println("left clicked");
      bleMouse.click(MOUSE_LEFT);

      drv.setWaveform(0, 17);  // strong click 100%, see datasheet part 11.2
      drv.setWaveform(1, 0);  // end of waveforms
      drv.go();
      // drv.setWaveform(0,0); //Stops Vibration

      click_mode = false;
      click_mode_frame_count = 0;

      delay(500);
    }
    if ((pitch_a < -50) && (pitch_a > -80)){ //Right click
      // Serial.println("right clicked");
      bleMouse.click(MOUSE_RIGHT);

      drv.setWaveform(0, 17);  // strong click 100%, see datasheet part 11.2
      drv.setWaveform(1, 0);  // end of waveforms
      drv.go();
      // drv.setWaveform(0,0); //Stops Vibration

      click_mode = false;
      click_mode_frame_count = 0;

      delay(500);
    }

    click_mode_frame_count++;
    if(click_mode_frame_count >= 100){
      // Serial.println("No input detected, going back to cursor mode");
      click_mode = false;
      click_mode_frame_count = 0;
    }
  }

 
  else{ /* CURSOR MODE*/

    /* PA sensor reading */
    delayMicroseconds(s_frame_period_micros);
    digitalWrite(SS, 0); //Assert CSB Low
    PA_object objs[16]; //initialize objects array
    PA_read_report(objs, 1); //read object data into objs array
    digitalWrite(SS, 1);  // deasserting CS seems to be required for next frame readout

    /* check if ble connected*/
    if(!bleMouse.isConnected()) {  
      char buffer[128];
      char *ptr = buffer;
      ptr += sprintf(ptr, "%d, %d\n", objs[0].cx,objs[0].cy);
      // Serial.print(buffer);
      return;
    }

    int x,y;
    // if object out of bounds, use last position
    if(objs[0].cx > 4094.0 || objs[0].cy > 4094.0){ // check if out of bounds
      x = last_x_pos;
      y = last_y_pos;
    }
    else{
      // left hand mode just wear the thing backwards, dont need to change rolling direction this way
      if (is_right_handed == true){
        y = (4095 - objs[0].cx) /4095.0 * res_x; // convert to screen coordinates
        x = (4095 - objs[0].cy) /4095.0 * res_y;
      }
      else{
        y = (objs[0].cx) /4095.0 * res_x; // convert to screen coordinates
        x = (objs[0].cy) /4095.0 * res_y;
      }
    }

    int dx = (x - last_x_pos); // possibly useful for other things?..
    int dy = (y - last_y_pos);

    int x_move = dx * sensitivity; // use these to move mouse
    int y_move = dy * sensitivity;

    // count frames if cursor still and not in corners
    if(std::abs(x-last_x_pos) < 5 && objs[0].cx < 4095.0 && objs[0].cy < 4095.0){
      static_cursor_frame_count++;
    }
    else{
      static_cursor_frame_count = 0;
    }
    // set last pos as current pos
    last_x_pos = x;
    last_y_pos = y;

    // move mouse, print sensor data if not connected to ble
    bleMouse.move(x_move,y_move,0,0);

    // enter click mode here
    if(static_cursor_frame_count >= 200){
      click_mode = true;
      //Serial.println("entering click mode");
      static_cursor_frame_count = 0; // reset static cursor counter

      drv.setWaveform(0, 37);  // strong click 100%, see datasheet part 11.2
      drv.setWaveform(1, 0);  // end of waveforms
      drv.go();

      // if click mode enable is not set, just dont go to click mode
      if (click_enabled == false){
        click_mode = false;
      }

    }
  }

  delay(frametime);
  
 }
 

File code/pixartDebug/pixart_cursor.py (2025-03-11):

import numpy as np
import serial
import pyautogui
import time
from scipy.spatial import distance
pyautogui.FAILSAFE = False

class IRCursorController:
    def __init__(self, sensor_interface):
        # Sensor interface that provides point coordinates
        self.sensor = sensor_interface
        
        # Sensitivity of mouse movement (adjust as needed)
        self.sensitivity = 2.0
        
        # Previous centroid position
        self.prev_centroid = None
        
        # Previous identified points (for tracking consistency)
        self.prev_identified_points = None
        
        # Rectangle pattern dimensions 
        self.rectangle_width = 70e-3  # Long side
        self.rectangle_height = 40e-3 # Short side
        
        # Expected rectangular pattern (relative coordinates)
        self.reference_pattern = np.array([
            [0, 0],                          # Top-left
            [self.rectangle_width, 0],       # Top-right
            [0, self.rectangle_height],      # Bottom-left
            [self.rectangle_width, self.rectangle_height]  # Bottom-right
        ], dtype=np.float32)
        
        # Pixart PAJ7025R3 intrinsic parameters (from datasheet)
        focal_length_mm = 0.378e-3  # 0.378mm
        sensor_width_mm = 11e-6  # 11um
        pixel_resolution = 98  # 98x98 pixels
        fx = fy = focal_length_mm / sensor_width_mm
        cx = cy = pixel_resolution / 2
        self.focal_length = (fx, fy)  # fx, fy
        self.principal_point = (cx, cy)  # cx, cy
        
        # Flag to check if system is calibrated
        self.is_calibrated = False
        
        # Threshold for minimum brightness to consider a point valid
        self.min_brightness = 50
        
        # Threshold for minimum area to consider a point valid
        self.min_area = 10
        
        # Last known aspect ratio of the rectangle
        self.last_aspect_ratio = self.rectangle_width / self.rectangle_height

    def get_led_points(self):
        """Get LED points from the sensor"""
        # Get raw data from sensor
        points_data = self.sensor.get_points()
        
        # Filter points by brightness and area
        valid_points = []
        for point in points_data:
            x, y = point['position']
            # brightness = point['brightness']
            # area = point['area']
            valid_points.append((x, y))

            if len(valid_points) >= 4:
                break
        
        return valid_points

    def calculate_side_lengths(self, points):
        """
        Calculate the side lengths of the quadrilateral formed by the points
        Returns a list of 4 side lengths in clockwise order
        """
        sides = []
        # print(f"side length func got input points {points}")
        # Assuming points are in order: top-left, top-right, bottom-right, bottom-left
        for i in range(4):
            next_i = (i + 1) % 4
            side_length = distance.euclidean(points[i], points[next_i])
            sides.append(side_length)
        return sides

    def identify_rectangle_pattern(self, points):
        """
        Identify the rectangular pattern regardless of orientation
        Returns the points in order: top-left, top-right, bottom-right, bottom-left (clockwise)
        """
        if len(points) != 4:
            print("hi")
            return None
        
        # Create all possible point orderings (24 permutations)
        # But we can optimize by only checking 4 rotations of each pattern
        centroid = np.mean(points, axis=0)
        
        # Sort points by angle around centroid
        angles = []
        for point in points:
            angle = np.arctan2(point[1] - centroid[1], point[0] - centroid[0])
            angles.append(angle)
        
        # Sort points by angle
        sorted_points = [p for _, p in sorted(zip(angles, points), key=lambda pair: pair[0])]
        
        # Generate 4 possible clockwise orderings (rotations)
        possible_orderings = []
        for i in range(4):
            ordering = sorted_points[i:] + sorted_points[:i]
            possible_orderings.append(ordering)
        
        # Find the ordering that best matches a rectangle
        best_ordering = None
        best_score = float('inf')
        
        for ordering in possible_orderings:
            # Calculate side lengths
            sides = self.calculate_side_lengths(ordering)
            
            # In a rectangle, opposite sides should be equal
            # Calculate the difference between opposite sides
            side_diff1 = abs(sides[0] - sides[2])
            side_diff2 = abs(sides[1] - sides[3])
            
            # Calculate aspect ratio
            longer_side = max(sides[0], sides[1])
            shorter_side = min(sides[0], sides[1])
            aspect_ratio = longer_side / shorter_side if shorter_side > 0 else float('inf')
            
            # How close is this to our expected aspect ratio?
            aspect_diff = abs(aspect_ratio - self.last_aspect_ratio)
            
            # Score based on side differences and aspect ratio
            score = side_diff1 + side_diff2 + aspect_diff
            
            if score < best_score:
                best_score = score
                best_ordering = ordering
        
        # If we found a good match, update the last known aspect ratio
        if best_ordering and best_score < 1.0:  # Threshold for "good enough" match
            sides = self.calculate_side_lengths(best_ordering)
            longer_side = max(sides[0], sides[1])
            shorter_side = min(sides[0], sides[1])
            self.last_aspect_ratio = longer_side / shorter_side

        print(f"ur mom {best_ordering}")
        
        return np.array(best_ordering, dtype=np.float32) if best_ordering else None
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

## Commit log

2025-01-07 added code for imu rotation tests
2025-01-08 added print_sensor.ino from trzy, added detailed comments
2025-01-08 added more commenting to print_sensor.ino
2025-01-08 updated print_sensor.ino in debugging process
2025-01-09 updated print_sensor.ino for debugging
2025-01-09 remove print_settings line in loop
2025-01-12 PIXART sensor pcb
    [PixArt-2024-12-01-14-14-13.sch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]
2025-01-16 Pixart PCB Second Iteration
    [PixArt-2024-12-01-14-14-13.sch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]
2025-01-17 reorganized folders
    [PixArt-2024-12-01-14-14-13.sch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]
2025-01-18 added 2d visual test video, and image of LED setup
2025-01-28 made new code to get position of camera in 3d space using pixart data
2025-02-25 added mouse cursor code, added to docs and pcb folders
2025-02-25 fixed get_points function by changing tuple format
    [pixart_cursor.py]
2025-02-26 added ble test to main to start testing moving mouse using esp32
2025-03-05 esp code dont print settings when initializing
2025-03-05 python cursor code fix
    [pixart_cursor.py]
2025-03-05 cleaned up gitignore files that were already in the repo
    [Pixart pcb-B_Cu.gbr, Pixart pcb-B_Mask.gbr, Pixart pcb-B_Paste.gbr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]
2025-03-11 Main PCB
    [MainPCB.kicad_pcb, MainPCB.kicad_sch, bom.csv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]
2025-03-11 dont print debug
2025-03-25 added motor driver package
